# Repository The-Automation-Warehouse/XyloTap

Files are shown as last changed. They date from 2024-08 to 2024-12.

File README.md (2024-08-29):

# XyloTap

WORK IN PROGRESS

Made as part of Arcade Hack Club

Used github copilot when writing code and readme

## Introduction

This project is and attempt to create a xylaphone that can play itself.
In the end the user simply uploads a midi file to an SD card and the xylaphone will play the song.
The ultimate goal is to play RUSH E by Street Music Boss.
I also want to have a dedicated button for each note so that the user can play the xylaphone manually like a piano.

## Hardware

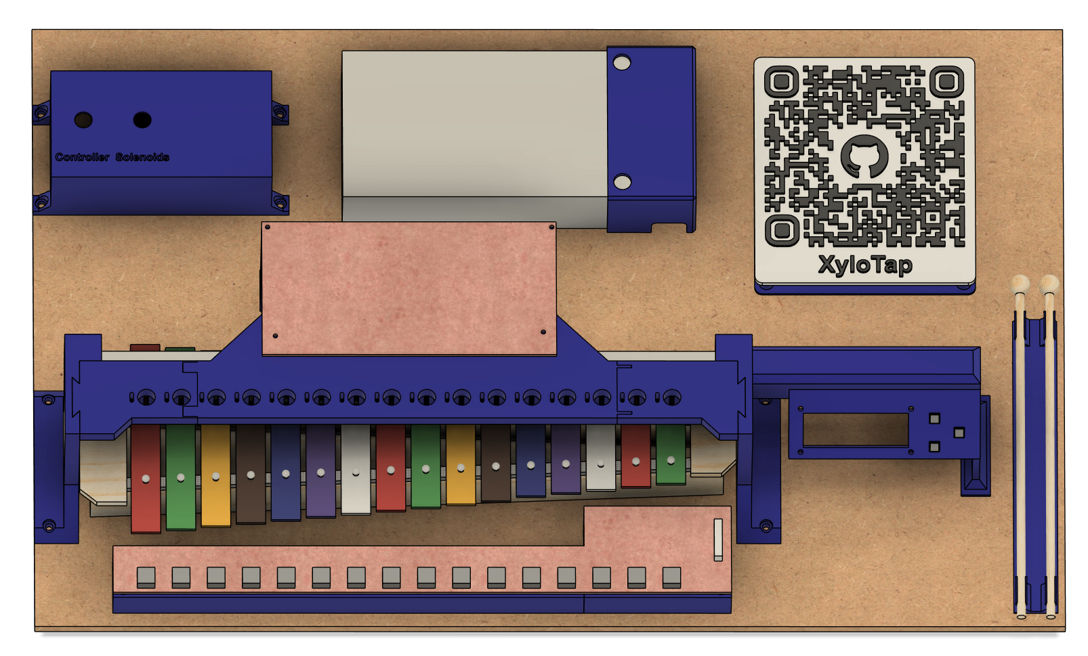
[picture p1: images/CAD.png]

CAD - Work in progress

I started with the biggest xylaphone (16 keys) I could find cheaply online and then designed the rest of the hardware around it.
A 3D printed structure holds the soleinoids in place and allows adjustment to make them hit the keys correctly.
I used an 8mm thick MDf board as the base.

## Electronics

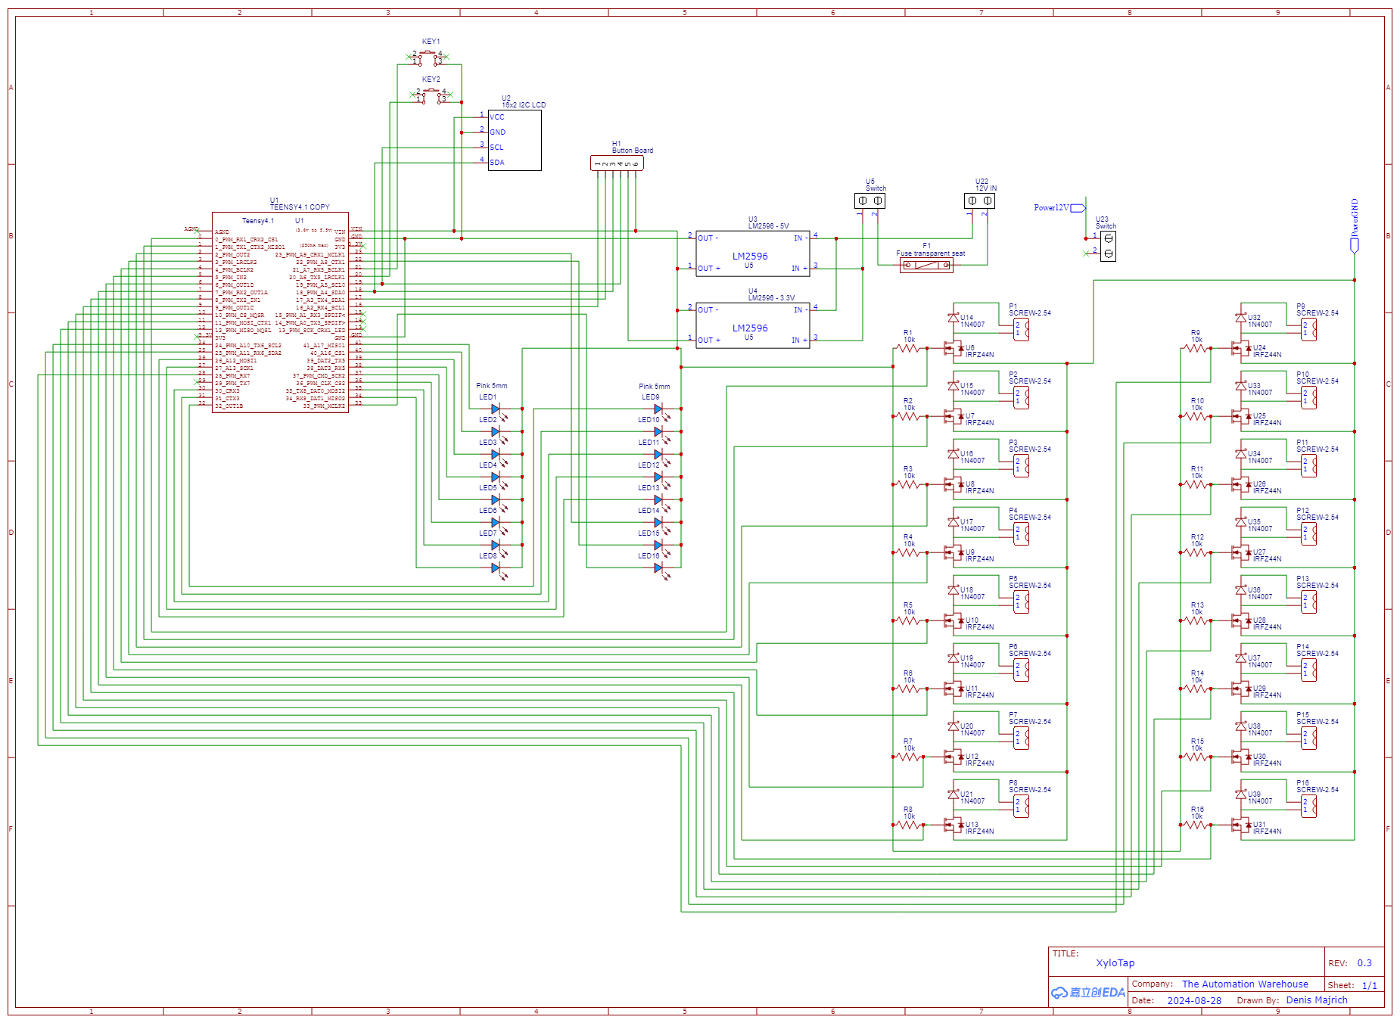
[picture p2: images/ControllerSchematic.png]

Controller Schematic - Work in progress

The brains of the operation is a Teensy 4.1 microcontroller.
Each solenoid is controlled by an IRFZ44N MOSFET and has an LED to indicate when it is active.

The user interface consists of a 16x2 I2C LCD screen, and 3 buttons.

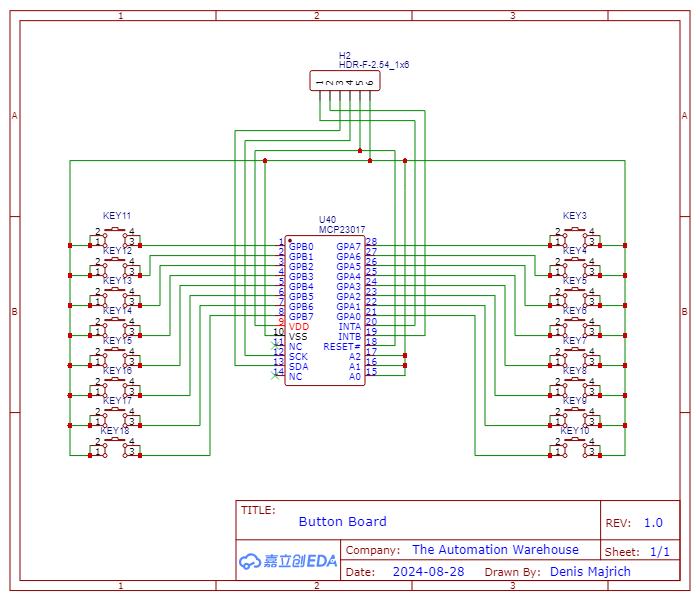
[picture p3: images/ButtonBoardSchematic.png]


The individual key buttons are mounted on a separate board through the MCP23017 I2C GPIO expander due to the limited number of pins on the Teensy.

Everything is powered by a 12V 25A power supply with two buck converters for the 5V and 3.3V rails to power the control electronics.

## Software

Have not started on the software yet.

## Current Status

I have the electronics and mechanical build mostly planned out.
I have machined and soldered the first part of the button board.
I am working on the rest of the button board and finishing the CAD.
I am waiting for the control electronics to arrive.

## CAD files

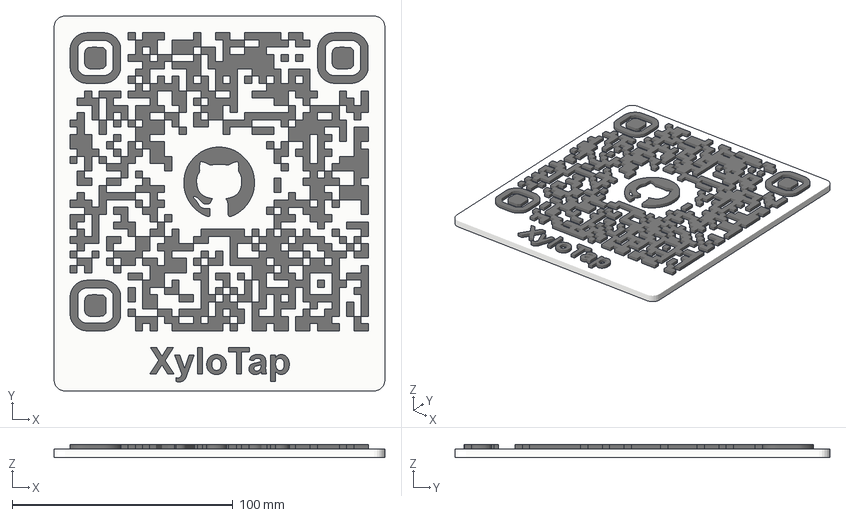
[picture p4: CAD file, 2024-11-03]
CAD/STLs/QR Code.3mf
150.0 x 170.0 x 6.00 mm
QR Code Base

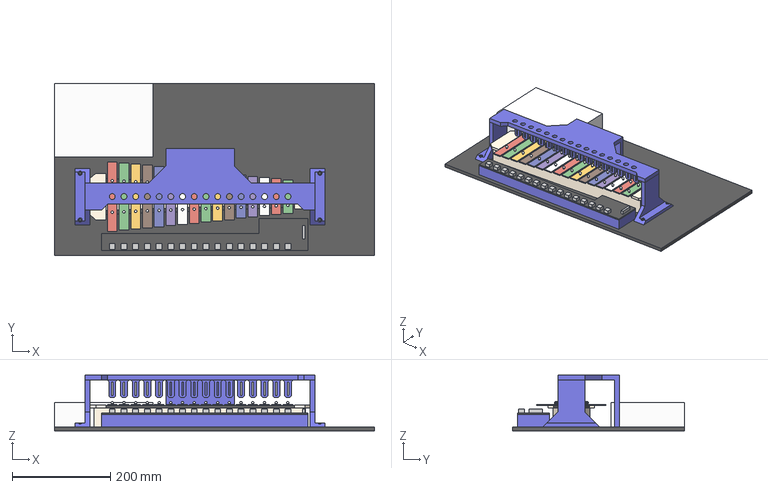
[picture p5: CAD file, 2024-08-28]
CAD/XyloTap.step
650.0 x 350.0 x 113.0 mm

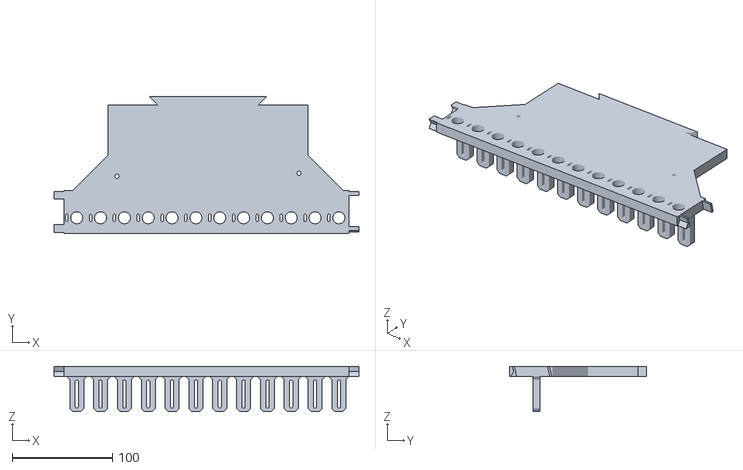
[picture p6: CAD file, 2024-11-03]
CAD/STLs/TopMiddle.stl
304.6 x 136.5 x 45.0

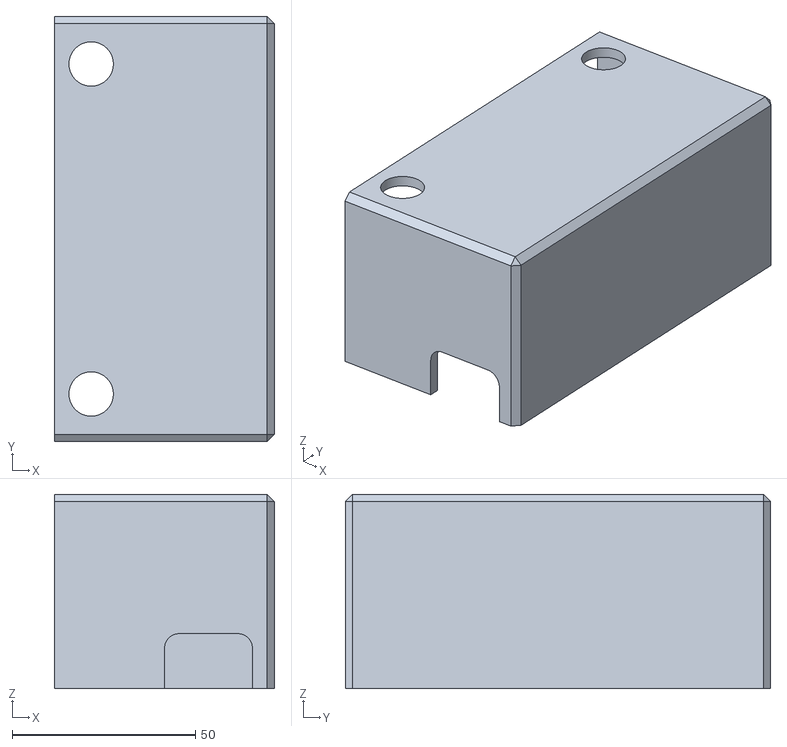
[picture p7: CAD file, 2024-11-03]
CAD/STLs/PSU Cover.stl
60.0 x 116.0 x 53.0

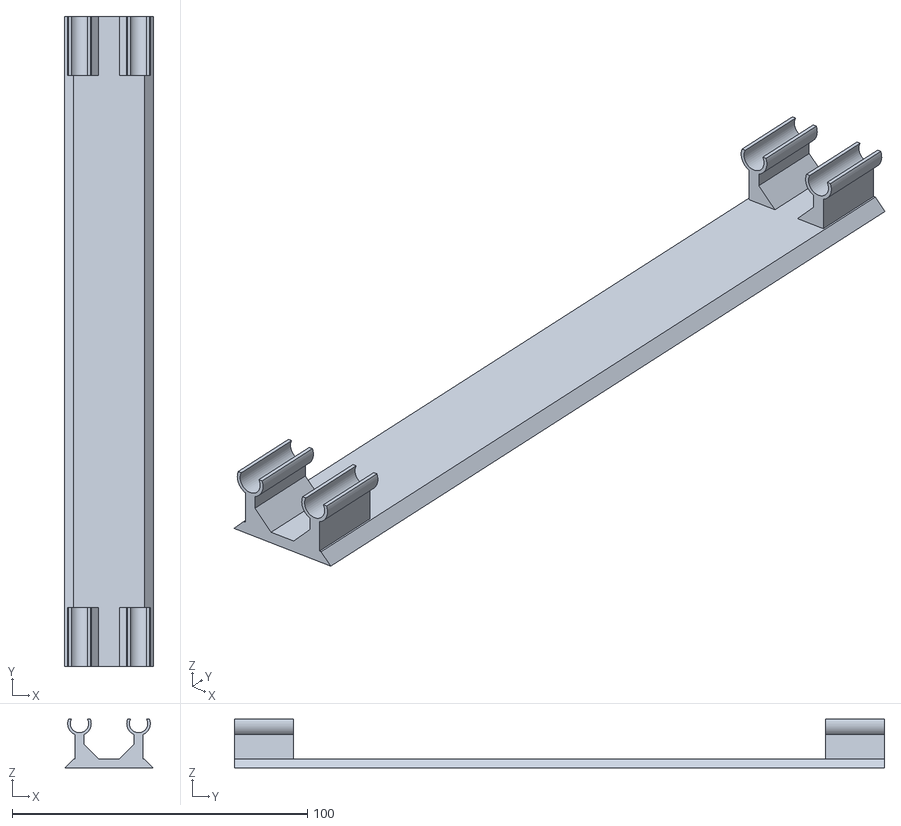
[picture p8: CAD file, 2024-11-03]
CAD/STLs/Stick Stand.stl
30.0 x 220.0 x 16.5

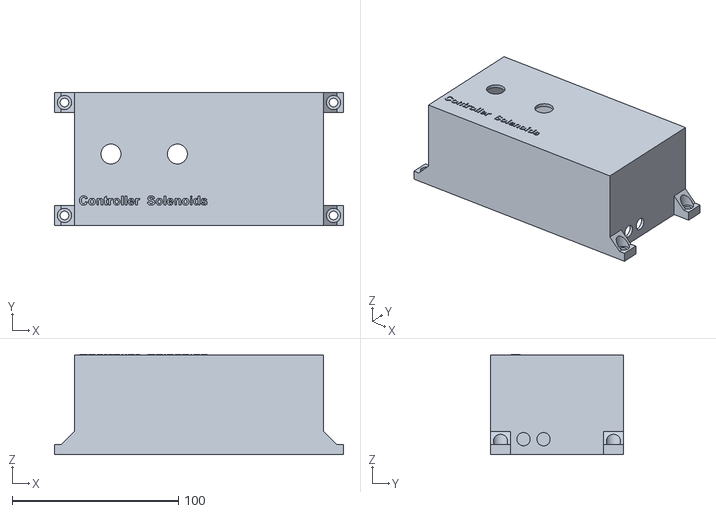
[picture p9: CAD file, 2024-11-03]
CAD/STLs/AC13 + Switch box.stl
174.0 x 80.0 x 60.4

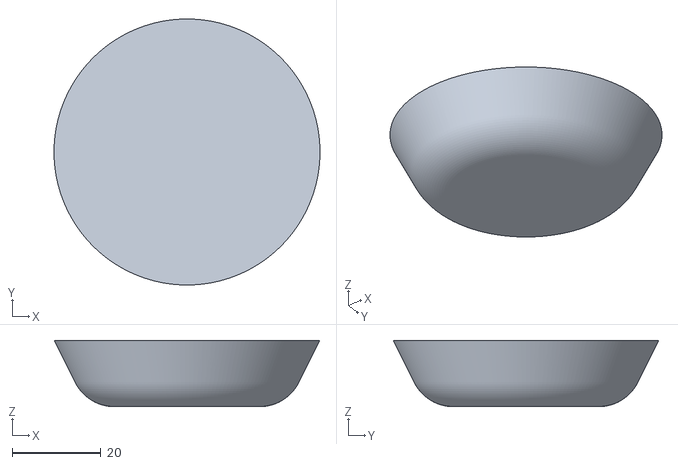
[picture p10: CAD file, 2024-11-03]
CAD/STLs/Foot_6x.stl
60.0 x 60.0 x 15.0

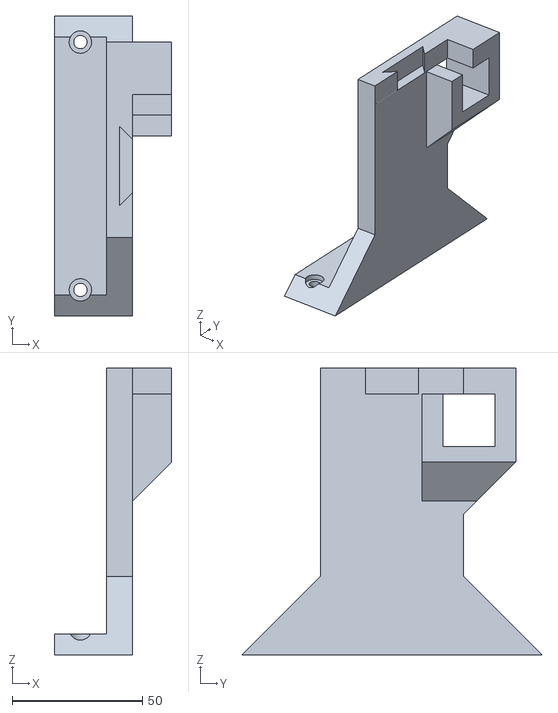
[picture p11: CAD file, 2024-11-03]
CAD/STLs/Left Leg.stl
45.0 x 115.0 x 110.0

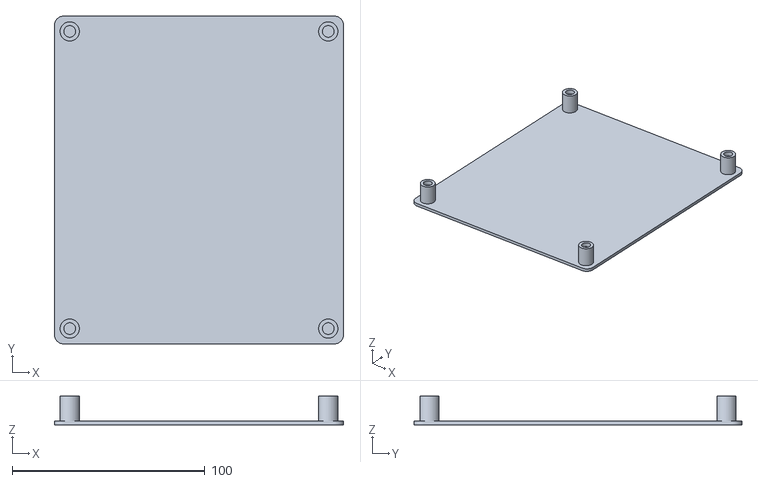
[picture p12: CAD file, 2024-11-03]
CAD/STLs/QR Stand.stl
150.0 x 170.0 x 15.0

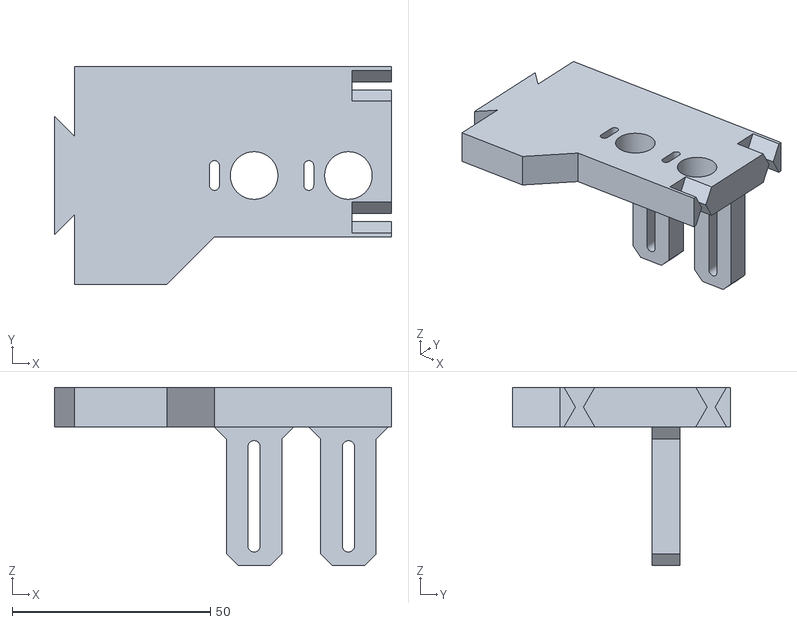
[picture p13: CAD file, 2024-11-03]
CAD/STLs/LeftMiddle.stl
85.0 x 55.0 x 45.0

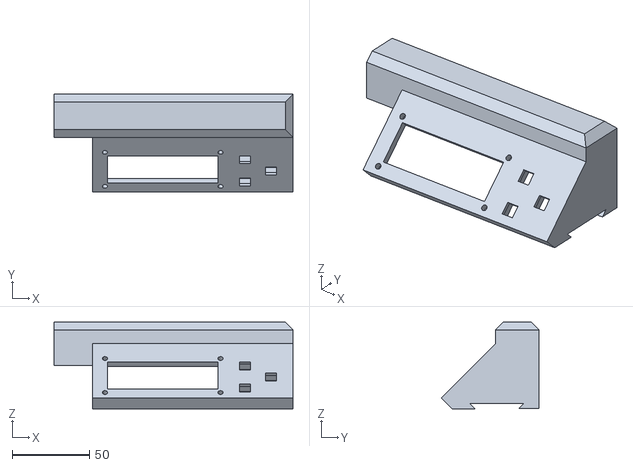
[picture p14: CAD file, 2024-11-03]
CAD/STLs/UI Mount.stl
155.0 x 63.4 x 56.3

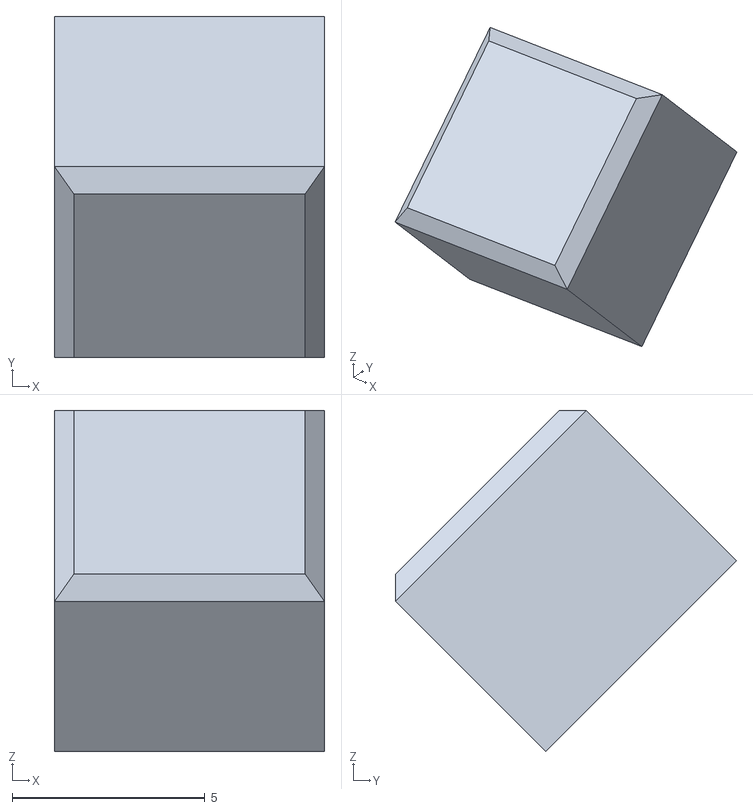
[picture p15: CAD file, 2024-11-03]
CAD/STLs/Button_3x.stl
7.00 x 8.84 x 8.84

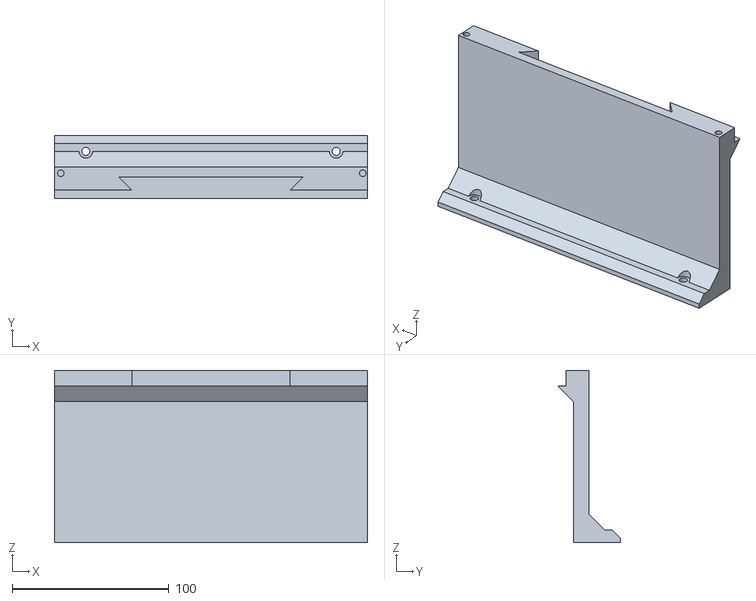
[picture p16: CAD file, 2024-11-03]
CAD/STLs/Back Leg.stl
200.0 x 40.0 x 110.0

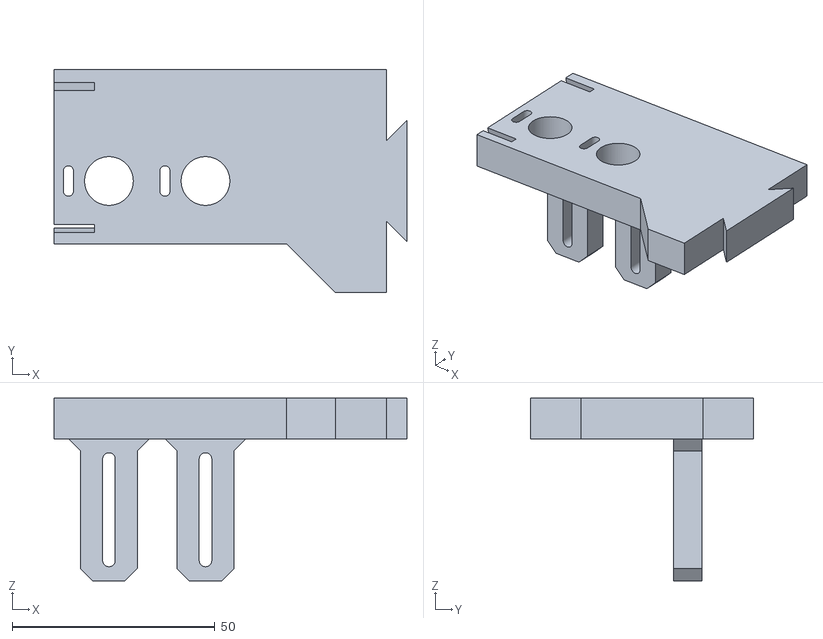
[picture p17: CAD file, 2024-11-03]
CAD/STLs/RightMiddle.stl
87.0 x 55.0 x 45.0

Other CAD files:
CAD/STLs/Right Leg.stl
CAD/STLs/UI Leg.stl
CAD/STLs/QR Code.stl

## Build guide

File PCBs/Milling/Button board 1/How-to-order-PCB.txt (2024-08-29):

How to Order PCB

Please refer to:
https://docs.easyeda.com/en/PCB/Order-PCB

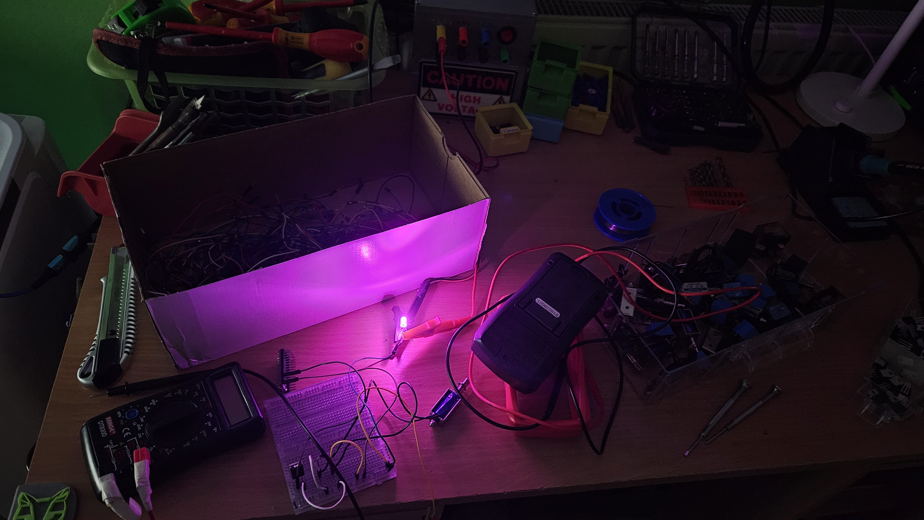
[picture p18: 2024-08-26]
making of/Pink LED.jpg

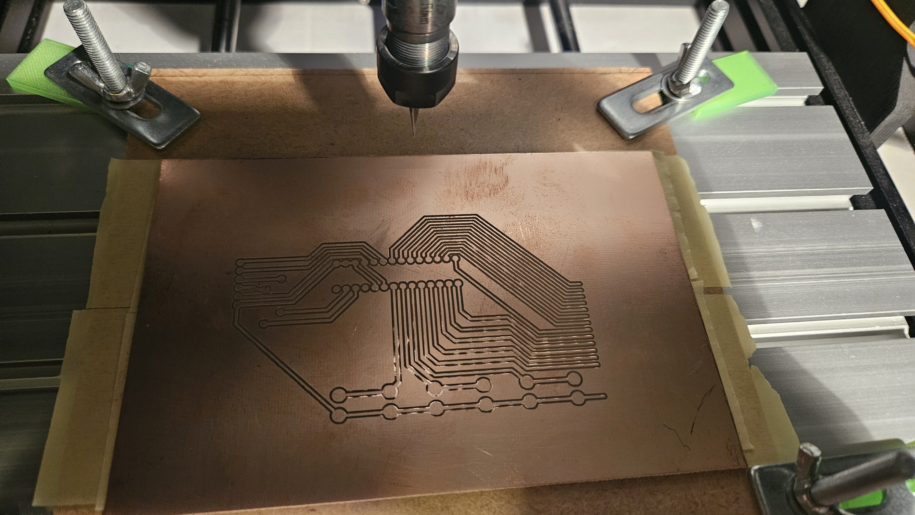
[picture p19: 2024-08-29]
making of/Milling 2-2.jpg

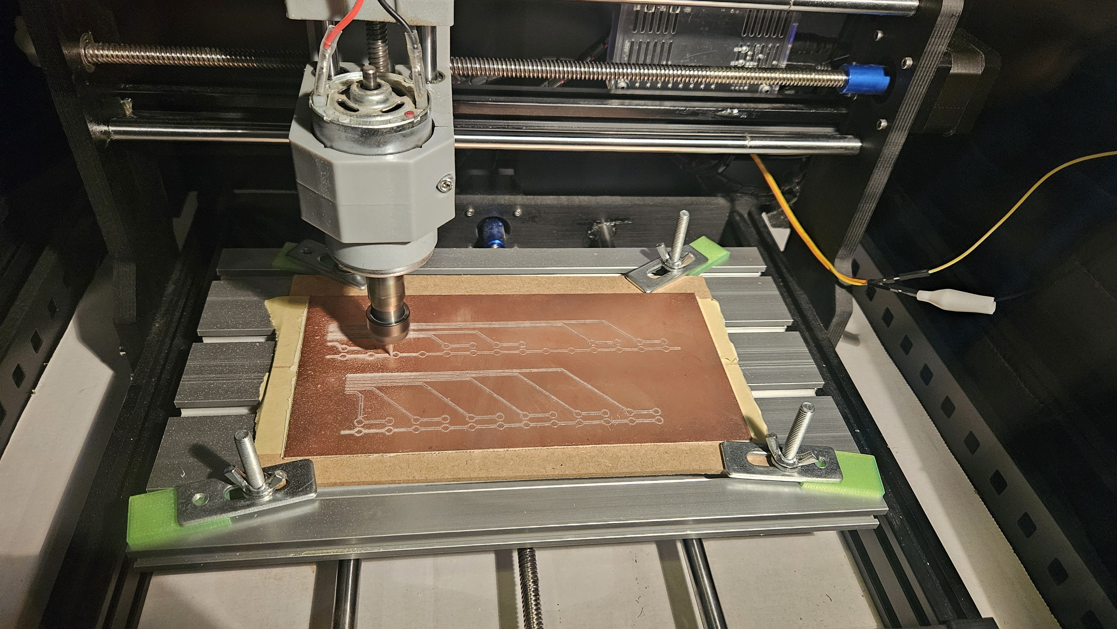
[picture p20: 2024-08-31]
making of/Milling 3-3.jpg

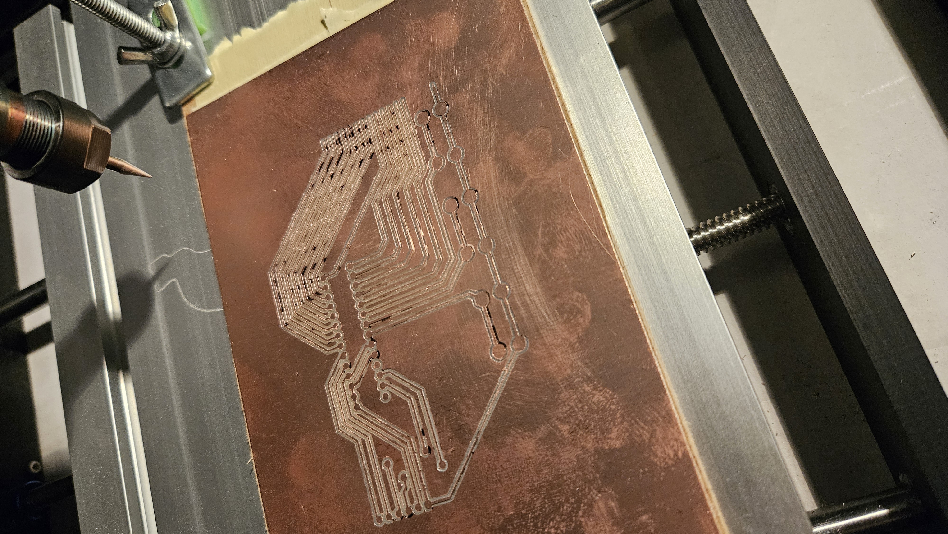
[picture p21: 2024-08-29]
making of/Milling 1 - Failed.jpg

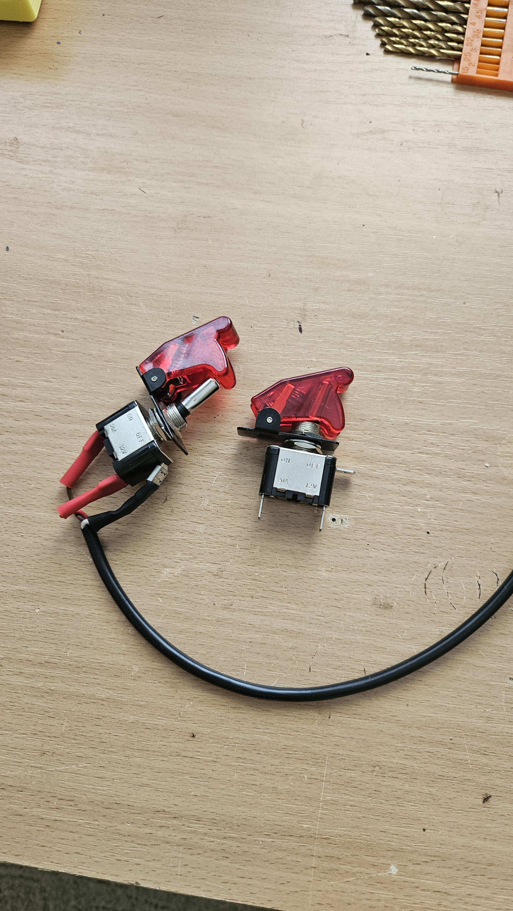
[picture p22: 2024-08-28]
making of/Switches.jpg

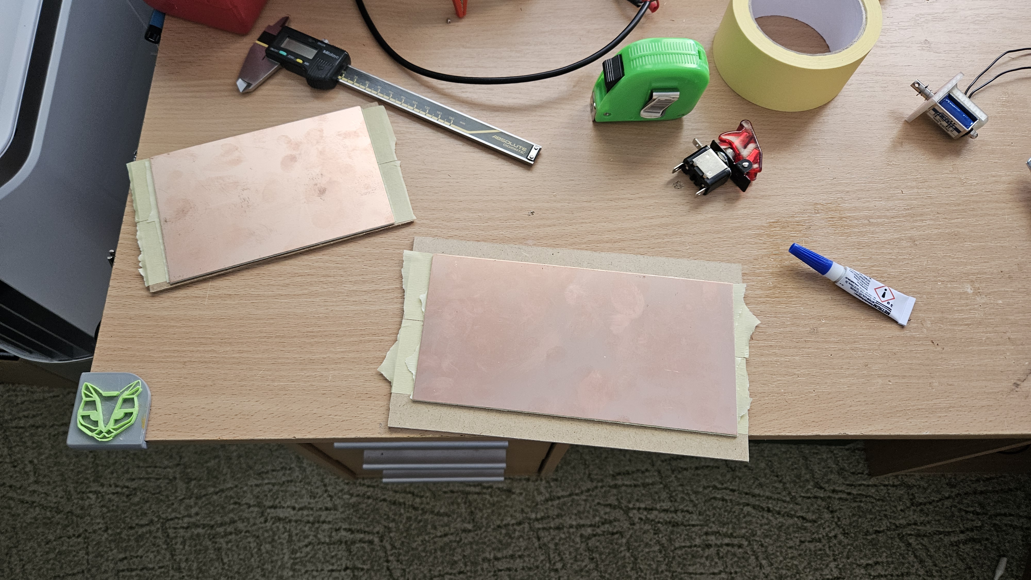
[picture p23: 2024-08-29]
making of/Copper clads.jpg

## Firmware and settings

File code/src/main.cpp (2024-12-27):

#include <Arduino.h>
#include <Adafruit_MCP23X08.h>
#include <Adafruit_MCP23X17.h>
#include <Wire.h>
#include <LiquidCrystal_I2C.h>
#include <SPI.h>
#include <SdFat.h>
#include <IntervalTimer.h>
#include <MD_MIDIFile.h>
#include "helperFunctions.h"
#include <iostream>

// The keys are CDEFGAHCDEFGAHCD


const uint8_t solenoids[16] = {0, 2, 4, 6, 1, 3, 5, 7, 28, 25, 24, 12, 11, 10, 9, 8};
unsigned long solenoidOnDurations[16] = {18, 18, 18, 19, 16, 16, 16, 15, 15, 15, 17, 16, 16, 16, 16, 16};
unsigned long solenoidOnTimes[16];
bool solenoidStates[16];
const uint8_t leds[16] = {41, 40, 39, 38, 37, 36, 35, 34, 32, 31, 30, 27, 26, 23, 22, 33};

extern void strikeKey(int key);
extern void turnOffKey(int key);
extern void checkSolenoids();

IntervalTimer solenoidTimer;

#define YellowLED 15
#define BlueLED 14

#define UP_BUTTON 29
#define DOWN_BUTTON 20
#define CONFIRM_BUTTON 21

// LCD
LiquidCrystal_I2C lcd(0x27, 16, 2);
int menuIndex = 0;
bool refreshMenu = true;
String songList[32];

// SDFat

// SDCARD_SS_PIN is defined for the built-in SD on some boards.
#ifndef SDCARD_SS_PIN
const uint8_t SD_CS_PIN = SS;
#else  // SDCARD_SS_PIN
// Assume built-in SD is used.
const uint8_t SD_CS_PIN = SDCARD_SS_PIN;
#endif  // SDCARD_SS_PIN

// Try max SPI clock for an SD. Reduce SPI_CLOCK if errors occur.
#define SPI_CLOCK SD_SCK_MHZ(50)

// Try to select the best SD card configuration.
#if HAS_SDIO_CLASS
#define SD_CONFIG SdioConfig(FIFO_SDIO)
#elif  ENABLE_DEDICATED_SPI
#define SD_CONFIG SdSpiConfig(SD_CS_PIN, DEDICATED_SPI, SPI_CLOCK)
#else  // HAS_SDIO_CLASS
#define SD_CONFIG SdSpiConfig(SD_CS_PIN, SHARED_SPI, SPI_CLOCK)
#endif  // HAS_SDIO_CLASS
SdFat SD;
MD_MIDIFile SMF;

extern void midiCallback(midi_event *pev);
extern int midiNoteToKey(int midiNote);
extern void testPattern();
void playSong(String name);
void stopSong();

// MCP23017
#define INTA_PIN 16
#define INTB_PIN 17
Adafruit_MCP23X17 mcp;
extern void handleMCP();


void resetTeensy() {digitalWrite(BlueLED, LOW);  SCB_AIRCR = 0x05FA0004;}

void setup() {

  Serial.begin(115200);
  Serial.println("Initializing...");

  pinMode(CONFIRM_BUTTON, INPUT_PULLUP);
  pinMode(UP_BUTTON, INPUT_PULLUP);
  pinMode(DOWN_BUTTON, INPUT_PULLUP);

  pinMode(YellowLED, OUTPUT);
  pinMode(BlueLED, OUTPUT);
  digitalWrite(YellowLED, HIGH);
  digitalWrite(BlueLED, LOW);

  for (uint8_t i = 0; i < 16; i++) {
    digitalWrite(BlueLED, HIGH);
    pinMode(solenoids[i], OUTPUT);
    digitalWrite(solenoids[i], LOW);
    solenoidOnTimes[i] = 0;
    solenoidStates[i] = false;
    delay(50);
    digitalWrite(BlueLED, LOW);
    delay(50);
  }
  for (uint8_t i = 0; i < 16; i++) {
    digitalWrite(BlueLED, HIGH);
    pinMode(leds[i], OUTPUT);
    digitalWrite(leds[i], HIGH);
    delay(50);
    digitalWrite(BlueLED, LOW);
    delay(50);
  }

  Serial.println("Solenoids ready.");

  solenoidTimer.begin(checkSolenoids, 500);

  Serial.println("Timer running.");


  // LCD
  lcd.init();
  lcd.backlight();
  lcd.setCursor(0, 0);
  lcd.print("Initializing...");
  delay(300);

  // SD
  if (!SD.begin(SD_CONFIG)) {
    Serial.println("SD Error.");
    lcd.clear();
    lcd.setCursor(0, 0);
    lcd.print("SD Error.");
    while (1) {
      if (digitalRead(CONFIRM_BUTTON) == LOW) {
        resetTeensy();
      }
    }
  } else {
    Serial.println("SD Card OK.");
    lcd.clear();
    lcd.setCursor(0, 0);
    lcd.print("SD Card OK.");
  }


  // MCP23017
  if (!mcp.begin_I2C()) {
    Serial.println("MCP Error.");
    while (1) {
      if (digitalRead(CONFIRM_BUTTON) == LOW) {
        resetTeensy();
      }
    }
  } else {
    Serial.println("MCP Initialized.");
  }

  pinMode(INTA_PIN, INPUT_PULLUP);
  pinMode(INTB_PIN, INPUT_PULLUP);

  attachInterrupt(digitalPinToInterrupt(INTA_PIN), handleMCP, FALLING);
  attachInterrupt(digitalPinToInterrupt(INTB_PIN), handleMCP, FALLING);

  Serial.println("MCP Interrupts attached.");

  mcp.clearInterrupts();
  for (uint8_t i = 0; i < 16; i++) {
    mcp.disableInterruptPin(i);
  }

  Serial.println("MCP Interrupts disabled.");

  for (uint8_t i = 0; i < 16; i++) {
    mcp.pinMode(i, INPUT_PULLUP);
  }

  mcp.setupInterrupts(false, false, LOW);
  
  for (uint8_t i = 0; i < 16; i++) {
    mcp.setupInterruptPin(i, CHANGE);
  }

  Serial.println("MCP Interrupts enabled.");

  // MIDI
  SMF.begin(&SD);
  SMF.setMidiHandler(midiCallback);
  SMF.looping(false);

  lcd.clear();
  lcd.setCursor(0, 0);
  lcd.print("XyloTap ready!");
  delay(500);

  Serial.println("Looping...");

  digitalWrite(BlueLED, HIGH);
}

void loop() {

  // Show a menu consisting of the list of songs from the SD card
  // The user can scroll through the list using the UP and DOWN buttons
  // The user can select a song using the CONFIRM button

  // If a song is selected, play the song
  // If the song is playing, the user can stop the song by clicking the CONFIRM button

  Serial.println("Test pattern.");
  testPattern();

  Serial.println("Menu loop.");

  lcd.clear();
  lcd.setCursor(0, 0);
  lcd.print("Select a song:");
  lcd.setCursor(0, 1);
  // Load the songs from the SD card to the songList array
  FsFile dir = SD.open("/");
  int songCount = 0;
  while (true) {
    SdFile entry;
    if (!entry.openNext(&dir, O_RDONLY)) {
        break;
    }
    if (!entry) {
      break;
    }
    if (entry.isDirectory()) {
      continue;
    }
    char name[32];
    entry.getName(name, 32);
    songList[songCount] = String(name);
    songCount++;
    entry.close();
  }

  // Print the song list to the serial monitor
  for (int i = 0; i < songCount; i++) {
    Serial.println(songList[i]);
  }

  while (true) {
    if (digitalRead(UP_BUTTON) == LOW) {
      menuIndex--;
      if (menuIndex < 0) {
        menuIndex = songCount - 1;
      }
      refreshMenu = true;
    }
    if (digitalRead(DOWN_BUTTON) == LOW) {
      menuIndex++;
      if (menuIndex >= songCount) {
        menuIndex = 0;
      }
      refreshMenu = true;
    }
    if (digitalRead(CONFIRM_BUTTON) == LOW) {
      playSong(songList[menuIndex]);
      break;
    }
    if (refreshMenu) {
      lcd.setCursor(0, 1);
      // Clear the line before printing the song name
      lcd.print("                ");
      lcd.setCursor(0, 1);
      // Remove the .mid or .MID extension from the song name
      String songName = songList[menuIndex];
      songName.replace(".mid", "");
      songName.replace(".MID", "");
      lcd.print(songName);
      refreshMenu = false;
      Serial.println("Menu refreshed.");
      delay(300);
    }
  }


}









void playSong(String name) {
  SMF.setFilename(name.c_str());
    int err = SMF.load(name.c_str());
    if (err != 0) {
      lcd.clear();
      lcd.setCursor(0, 0);
      lcd.print("Error loading file.");
      Serial.println("Error loading file.");
    } else {
      lcd.clear();
      lcd.setCursor(0, 0);
      lcd.print("Now playing: ");
      lcd.setCursor(0, 1);
      String songName = SMF.getFilename();
      songName.replace(".mid", "");
      songName.replace(".MID", "");
      lcd.print(songName);
      Serial.println("Now playing: " + songName);
    }
    // Wait for the button to be released
    delay(1000);
    while (digitalRead(CONFIRM_BUTTON) == LOW) {}

    attachInterrupt(digitalPinToInterrupt(CONFIRM_BUTTON), stopSong, FALLING);
    while (SMF.isEOF() == false && SMF.isPaused() == false) {
      // Play the MIDI file
      SMF.getNextEvent();
    }
    detachInterrupt(digitalPinToInterrupt(CONFIRM_BUTTON));
    Serial.println("Song ended.");
    lcd.clear();
    lcd.setCursor(0, 0);
    lcd.print("Song ended.");
    refreshMenu = true;
    SMF.close();
    SMF.pause(false);
    SMF.looping(false);
    // Wait for the button to be released
    delay(1000);
    while (digitalRead(CONFIRM_BUTTON) == LOW) {}
}



void stopSong() {
  refreshMenu = true;
  SMF.pause(true);
  Serial.println("Interrupted.");
}

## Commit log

2024-08-27 Started working on CAD
    [XyloTap.step]
2024-08-28 Started working on schematic
2024-08-28 Added a dedicated PCB for buttons
2024-08-28 Started working on Button board PCB
2024-08-28 Update Button Board PCB.json
2024-08-29 Finished the Button Board PCB design
2024-08-29 Started milling button board 1
    [Drill_PTH_Through.DRL, Drill_PTH_Through_Via.DRL, Gerber_BoardOutlineLayer.GKO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]
2024-08-29 Create Milling 1.jpg
2024-08-29 Create Milling 1 - Failed.jpg
2024-08-29 Create Milling 2.jpg
2024-08-29 Create Milling 2-2.jpg
2024-08-29 Finished the first button board
2024-08-29 Added milling files for button board 2
    [Drill_PTH_Through.DRL, Drill_PTH_Through_Via.DRL, Gerber_BoardOutlineLayer.GKO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]
2024-08-29 Started planning out the controller PCB
2024-08-30 Started controller PCB layout
2024-08-30 Switched to a profesionaly manufactured PCB
2024-08-30 Update Controller PCB.json
2024-08-31 Create Milling 3.jpg
2024-08-31 Create Milling 3-2.jpg
2024-08-31 Create Milling 3-3.jpg
2024-08-31 Finished button board milling
2024-08-31 Create Button board soldered.jpg
2024-08-31 Finished the button board mechanical build
2024-08-31 Working on mcp interrupts
2024-08-31 Made mcp interrupts work
2024-08-31 Create Button board finished.jpg
2024-11-03 Finished the build and code
    [AC13 + Switch box.stl, Back Leg.stl, Button_3x.stl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]
